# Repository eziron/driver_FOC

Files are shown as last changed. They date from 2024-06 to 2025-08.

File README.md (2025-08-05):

# EZFOC V1 - Controlador FOC para Motores Brushless

<p align="center">
  Vista frontal de la PCB EZFOC V1 ensamblada
  <br>
  <em>Vista frontal de la PCB EZFOC V1 completamente ensamblada.</em>
</p>

---

## 📜 Descripción General

**EZFOC V1** es mi proyecto de título con el cual obtuve el grado de Ingeniero de Ejecución en Electrónica. El proyecto se enfoca en el diseño, implementación y validación de un controlador de campo orientado (FOC) para motores brushless (BLDC), desarrollado desde cero abarcando tanto el diseño del **hardware (PCB)** como la programación del **firmware** en un microcontrolador de alto rendimiento **STM32H743VIT6**.

El principal objetivo del proyecto fue ofrecer una solución robusta y de altas prestaciones para aplicaciones exigentes, como la **robótica de competencia (robots de sumo)**, donde el control preciso de torque y velocidad, junto con la capacidad de manejar altas corrientes, es fundamental.

Para una referencia completa y detallada, puedes consultar el **[Esquemático del Hardware](esquematico%20PCB.pdf)** y el **[Manuscrito del Proyecto de Título](manuscrito%20Driver%20FOC%20rev%203%20300325.pdf)**, ambos disponibles en la raíz de este repositorio.

### ✨ Características Principales

*   **Control FOC (Field-Oriented Control):** Permite un control de torque suave y eficiente, desacoplando el flujo magnético del par motor.
*   **Hardware Personalizado:**
    *   PCB de 4 capas diseñada en Autodesk Eagle. Una parte del ensamblaje se realizó mediante el servicio de **PCBA de JLCPCB**, mientras que los componentes restantes fueron soldados manualmente.
    *   Inversor trifásico capaz de manejar altas corrientes (hasta 100A continuos por diseño, con MOSFETs en paralelo).
    *   Medición de corriente de fase **en línea (inline)**, a la salida de cada pierna del inversor, con resistencias shunt y amplificadores INA240.
    *   Soporte para encoder magnético (AS5047P) para una realimentación de posición precisa.
*   **Firmware de Alto Rendimiento:**
    *   Basado en un microcontrolador **STM32H743VIT6** (ARM Cortex-M7 @ 480 MHz).
    *   Lazo de control ejecutado a **48 kHz** en una interrupción de alta prioridad para garantizar el tiempo real.
    *   Uso intensivo de periféricos como Timers, ADC y DMA para minimizar la carga de la CPU.
    *   Comunicación USB (Virtual COM Port) para depuración y visualización de datos en tiempo real.
*   **Diseño Mecánico:** Incluye soportes y acoples para el motor y el encoder diseñados en Autodesk Inventor e impresos en 3D.

---

## 📂 Estructura del Repositorio

El repositorio está organizado en varios directorios clave que separan las diferentes partes del proyecto. Para un acceso rápido, el **esquemático final** (`esquematico PCB.pdf`) y el **manuscrito del proyecto** (`manuscrito Driver FOC...pdf`) se encuentran en la raíz del repositorio.

```
.
├── Firmware_H7/      # Código fuente del firmware para el STM32H7.
├── Hardware/         # Archivos de diseño de la PCB y modelos 3D.
├── datasheets/       # Hojas de datos de los componentes principales.
├── manuscrito/       # Documento de la tesis, gráficos y datos de validación.
├── fotos/            # Fotografías del hardware y montaje.
├── referencias/      # Documentos de referencia y papers utilizados.
└── util/             # Scripts y utilidades para depuración y análisis de datos.
```

### 🧠 `Firmware_H7`

Contiene todo el código fuente para el microcontrolador. El entorno de desarrollo es **VSCode** con la extensión `stm32-for-vscode`.

*   `Board/`: **Lógica de aplicación principal.** Aquí se implementan los módulos clave del controlador:
    *   `FOC.c/.h`: Algoritmo central de FOC (transformadas de Clarke, Park, etc.).
    *   `PID.c/.h`: Controladores PID para los lazos de corriente y velocidad.
    *   `encoder.c/.h`: Lógica para la lectura y procesamiento de datos del encoder.
    *   `state_machine.c/.h`: Máquina de estados para gestionar el funcionamiento del motor (calibración, run, stop).
*   `Core/`: Código base generado por **STM32CubeMX**.
    *   `Src/main.c`: Punto de entrada principal y bucle de baja prioridad.
    *   `Src/stm32h7xx_it.c`: Rutinas de servicio de interrupción (aquí vive el lazo FOC).
*   `Makefile` y `STM32-for-VSCode.config.yaml`: Archivos de configuración para la compilación gestionada por la extensión de VSCode.

### 🛠️ `Hardware`

Todos los archivos de diseño de la placa controladora "EZFOC V1".

*   `3D/`: Archivos de diseño mecánico (`.ipt`, `.iam` de Inventor) y modelos para impresión 3D (`.stl`) del soporte motor-encoder.
*   `EZFOC_V1.sch` y `EZFOC_V1.brd`: Archivos de esquemático y PCB de Autodesk Eagle.
*   `EZFOC_V1_bom.csv` y `EZFOC_V1_cpl.csv`: Lista de materiales (BOM) y archivo de posicionamiento (CPL) para el ensamblaje automatizado.
*   `libs/`: Librerías de componentes para Eagle, obtenidas de diversas fuentes y con algunas modificaciones menores.

### 📊 `manuscrito` y `util`

*   **`manuscrito/`**: Contiene el documento de la tesis en formato LaTeX (`.tex`), junto con todas las imágenes, gráficos y datos (`.csv`) utilizados para la validación del controlador.
*   **`util/`**: Herramientas de apoyo desarrolladas en Python.
    *   `debug_FOC.py`: Script para recibir datos del microcontrolador vía USB, graficarlos en tiempo real y guardarlos en CSV.
    *   `reloj bruto.py`: Script auxiliar para calcular y obtener las configuraciones de los PLLs para el sistema de reloj del STM32H7.
    *   `Debug_LOGS/`: Logs de datos capturados durante las pruebas.

---

## 🚀 Configuración y Uso

Este proyecto está configurado para ser compilado utilizando **Visual Studio Code** con la extensión `stm32-for-vscode`.
(idealmente en linux o wsl)

### Requisitos de Software

1.  **Visual Studio Code**: El editor principal.
2.  **Extensión `stm32-for-vscode`**: Búscala e instálala desde el marketplace de VSCode.
3.  **ARM GCC Toolchain**: El compilador. La extensión `stm32-for-vscode` suele guiar en su instalación.
4.  **STM32CubeProgrammer**: Herramienta para flashear el firmware en el microcontrolador.

---

## 📈 Futuras Mejoras y Problemas Conocidos

Este proyecto sienta una base sólida, pero existen varias áreas de mejora identificadas durante el desarrollo:

*   **Protección de Hardware**: Implementar un gate driver con protección anti-*shoot-through* integrada para mejorar la robustez del puente H.
*   **Optimización de Firmware**: Migrar el código a C++ y utilizar un sistema operativo de tiempo real como **FreeRTOS** para una mejor organización y escalabilidad.
*   **Filtrado de Señal**: Mejorar el filtrado de la corriente, ya sea con filtros analógicos pasivos en la PCB o algoritmos de filtrado digital más avanzados.
*   **Compensación de *Cogging Torque***: Implementar un algoritmo de calibración para reducir las vibraciones del motor a bajas velocidades.

## ✒️ Autor

*   **Rodrigo Fuentes Pedreros** - [eziron](https://github.com/eziron)

Un proyecto desarrollado para la **Universidad del Bío-Bío, Facultad de Ingeniería**.

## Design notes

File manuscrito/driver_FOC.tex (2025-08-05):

\documentclass[11pt]{report}
\usepackage[spanish]{babel}
\usepackage[utf8]{inputenc}
\usepackage{graphicx}
\usepackage{geometry}
\usepackage{fancyhdr}
\usepackage{amsmath}
\usepackage{helvet}
\usepackage{titlesec}
\usepackage{setspace}
\usepackage{tocloft}
\usepackage{hyperref}
\usepackage{csquotes}
\usepackage{placeins}

\usepackage{pdfpages}

\setlength{\parskip}{0.5em}

\usepackage[style=numeric,sorting=none]{biblatex}
\addbibresource{referencias.bib}

\onehalfspacing
\renewcommand{\familydefault}{\sfdefault}

\geometry{
  letterpaper,
  left=3cm,
  right=2cm,
  top=2.5cm,
  bottom=2cm,
}

\addto\captionsspanish{
  \renewcommand{\contentsname}{Índice}
  \renewcommand{\tablename}{Tabla}
}
\renewcommand{\cftchapdotsep}{\cftdotsep}  % Para capítulos
\renewcommand{\cftsecdotsep}{\cftdotsep}   % Para secciones
\renewcommand{\cftsubsecdotsep}{\cftdotsep} % Para subsections

\titleformat{\chapter}[display]
  {\normalfont\Large\bfseries}
  {\chaptername\ \thechapter}
  {10pt}
  {\huge}
\titlespacing*{\chapter}{0pt}{-20pt}{20pt}  % Ajusta el espaciado aquí

\begin{document}

% Title page
\begin{titlepage}
	\begin{center}
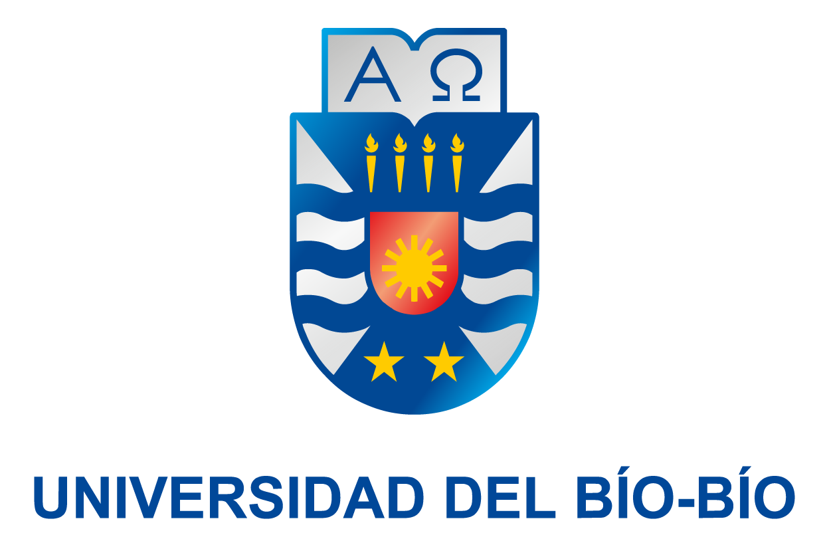
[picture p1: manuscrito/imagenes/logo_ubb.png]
		\\
		\normalsize FACULTAD DE INGENIERÍA\\
		DEPTO. INGENIERÍA ELÉCTRICA Y ELECTRÓNICA\\[2cm]

		\LARGE \textbf{``Implementación de un Controlador FOC para Motores Brushless con Encoder Utilizando STM32''}\\[6cm]

		\normalsize AUTOR:\\
		RODRIGO FUENTES PEDREROS\\
		\href{https://www.youtube.com/watch?v=dQw4w9WgXcQ}{\phantom{ASDF}}\\[2cm]

		SEMINARIO PARA OPTAR AL TÍTULO DE\\
		INGENIERO DE EJECUCIÓN EN ELECTRÓNICA\\[1cm]

		CONCEPCIÓN - CHILE\\
		AÑO 2024\\
	\end{center}
\end{titlepage}

% Back title page
\begin{titlepage}
	\begin{center}
		\\
		\normalsize FACULTAD DE INGENIERÍA\\
		DEPTO. INGENIERÍA ELÉCTRICA Y ELECTRÓNICA\\[2cm]

		\LARGE \textbf{``Implementación de un Controlador FOC para Motores Brushless con Encoder Utilizando STM32''}\\[5cm]

		\normalsize AUTOR\\
		RODRIGO FUENTES PEDREROS\\[3cm]

		\large PROFESOR GUÍA:\\
		\large ANGEL ERNESTO RUBIO\\[1cm]
		\large PROFESORES GUÍA ADJUNTO:\\
		\large PEDRO \href{https://youtu.be/UJwA7hu3aug?si=OvcJZs2QosQupum7&t=50}{MELIN} COLOMA
	\end{center}
\end{titlepage}

\normalsize
\pagenumbering{arabic}
\setcounter{page}{3}

\newpage
\tableofcontents

\newpage
\listoffigures

%\newpage
\listoftables

\newpage
\chapter*{Resumen}
\addcontentsline{toc}{chapter}{Resumen}

Este trabajo aborda el diseño e implementación de un controlador de campo orientado (\emph{FOC}) para motores \emph{brushless} de corriente continua, incorporando un \emph{encoder} para la medición de la posición. En primera instancia, se revisan los fundamentos teóricos que sustentan la técnica \emph{FOC}, destacando su capacidad para desacoplar el flujo magnético del par motor, y la relevancia de las transformadas de Clarke y Park para simplificar el control de las corrientes en el estátor. Asimismo, se incluyen los conceptos principales de la Modulación por Vector Espacial (\emph{SVM}), esencial para la síntesis de las señales de salida del inversor.

Posteriormente, se detalla el diseño y la fabricación del \emph{hardware} de la solución, que comprende un inversor trifásico basado en MOSFETs, controladores de puerta (\emph{gate drivers}) y sensores de corriente de tipo \emph{shunt}, junto con los elementos de filtrado y protección necesarios. Se selecciona y acondiciona un motor \emph{brushless}, al cual se integra un \emph{encoder} magnético para la obtención de la posición del rotor. Además, se documentan los procesos de elaboración de la PCB y la disposición de sus pistas para manejar corrientes elevadas, considerando la disipación y la estabilidad del sistema.

En el ámbito del \emph{firmware}, se describen las estrategias de configuración de los periféricos del microcontrolador STM32, haciendo uso de \emph{STM32CubeMX} para la inicialización de temporizadores y convertidores A/D (\emph{ADC}). Se explica el flujo de ejecución principal y la rutina de interrupción encargada de efectuar la lectura de sensores, la aplicación de las transformadas de Clarke y Park, los controladores de corriente y velocidad, así como la generación de las señales PWM mediante \emph{SVM}.

Para validar el rendimiento del controlador, se efectúan pruebas de velocidad y par bajo distintas condiciones de carga, analizando la estabilidad de las corrientes y la rapidez de respuesta ante cambios en la referencia. Asimismo, se capturan datos en tiempo real para su posterior evaluación, confirmando que la implementación logra un control estable y preciso del motor. Se identifican, no obstante, algunos retos en escenarios extremos, motivando la propuesta de futuras mejoras en el diseño.

En síntesis, la solución presentada demuestra la factibilidad de implementar un controlador \emph{FOC} de altas prestaciones utilizando un STM32 de la serie H7, combinando técnicas de transformación en el dominio rotatorio y \emph{SVM} en el lazo de control. Las observaciones obtenidas abren la puerta a nuevas optimizaciones, tanto en el \emph{hardware} (filtrado, disipación y protección) como en el \emph{firmware} (estructuras de software, algoritmos de compensación y sistemas operativos en tiempo real), facilitando así el despliegue de aplicaciones en robótica competitiva y sistemas embebidos.

\newpage
\chapter{Introducción}
\section{Introducción general}
Cuando se habla de motores eléctricos de corriente continua, los motores sin escobillas destacan por su alto desempeño, siendo la opción preferida en aplicaciones como vehículos eléctricos, drones, robótica avanzada y robótica industrial.

Para los motores \textit{brushless}, existe una gran variedad de técnicas de control. Algunas de las más relevantes son el control trapezoidal, utilizado mayormente en drones; el control directo de torque (DTC), empleado principalmente en motores de media y alta potencia en ambientes industriales; y el control FOC, que se aplica mayormente en robótica. En este documento, se tratará únicamente esta última técnica.

Existen tres aspectos clave que diferencian cada técnica: el rizado de torque, el coste computacional y la complejidad del hardware necesario para su ejecución. En estos aspectos, el control FOC es uno de los que produce menor rizado de torque, aunque requiere un mayor coste computacional y hardware especializado.

Este proyecto presenta la implementación y validación de un controlador de campo orientado (FOC) para motores sin escobillas de corriente continua (BLDC). Además, se desarrolló la placa controladora utilizando un microcontrolador STM32 como núcleo principal.

\newpage
\section{Marco teórico}
\subsection{Motores \textit{brushless}}
Los motores \textit{brushless}, o motores sin escobillas de corriente continua (BLDC), son un tipo de motor trifásico síncrono que utiliza imanes permanentes en el rotor y bobinas en el estátor, el cual está formado por láminas de hierro con ranuras para alojar las bobinas. A diferencia de los motores de corriente continua con escobillas, los BLDC no emplean elementos mecánicos para conmutar la corriente en las bobinas. En su lugar, esta conmutación se realiza mediante un controlador electrónico \cite{frick2018bldc}, eliminando el rozamiento y el desgaste asociados a las escobillas, lo que mejora la eficiencia del sistema.

\begin{figure}[ht]
	\centering
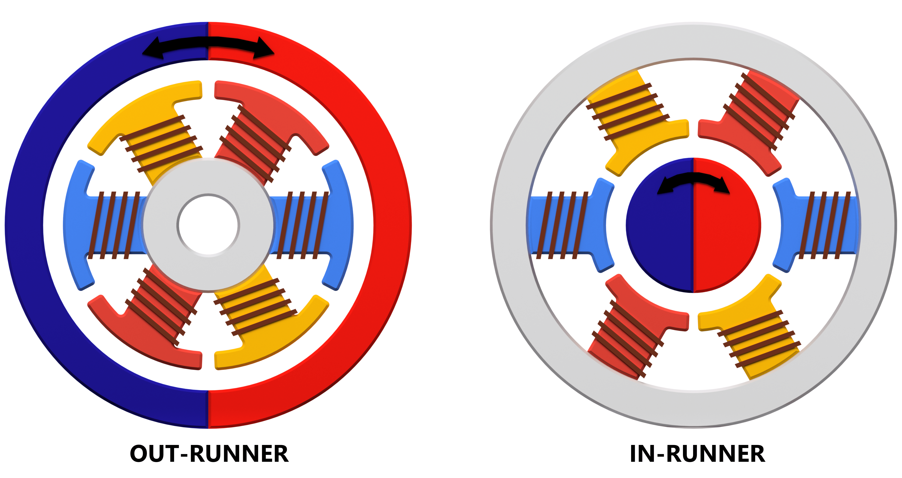
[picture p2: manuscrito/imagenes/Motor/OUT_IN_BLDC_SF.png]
	
	\caption{Esquema de motores sin escobillas (\textit{BLDC}).}
	\label{fig:motor_sin_escobillas}
\end{figure}
\FloatBarrier

Similar a los motores trifásicos de corriente alterna, estos pueden tener configuraciones de bobinado en delta o estrella \cite{Millet2022}. Además, como se ejemplifica en la figura \ref{fig:motor_sin_escobillas}, pueden presentar configuraciones \textit{in-runner}, donde los imanes están en el centro del eje con las bobinas en el exterior, o configuraciones \textit{out-runner} , donde los imanes se encuentran por fuera del motor, mientras que las bobinas están en el centro \cite{9774372}. Estos motores, al requerir una sincronización entre el campo magnético del estátor y el campo magnético del rotor, suelen utilizar encoders o sensores de efecto Hall para obtener información sobre la posición del eje y, de este modo, mantener una conmutación adecuada. No obstante, también es posible emplear técnicas \textit{sensorless} (sin sensor) para estimar la posición del rotor sin necesidad de sensores físicos \cite{Gualtieri2018_STEP}.

Los \textit{BLDC} se destacan por ofrecer una mayor densidad de potencia, mayor torque, mejores eficiencias y pueden alcanzar velocidades más altas. Sin embargo, al requerir de un controlador electrónico que se encargue de la conmutación para generar el movimiento del rotor, la complejidad y los costos asociados a su implementación son mayores \cite{AN885}.

\newpage
\subsection{Control Orientado de Campo (FOC)}
El control orientado de campo se basa en desacoplar el flujo electromagnético del par motor, permitiendo el control independiente de cada uno, aunque en este caso se realiza de forma indirecta, trabajando con las corrientes del estátor en vez de las variables reales de flujo y par. Este desacoplamiento se logra mediante la transformación de las variables trifásicas del motor, que están en un marco de referencia estacionario \(ABC\), hacia un marco de referencia rotatorio \(dq\) que gira en sincronía con el rotor del motor \cite{power_conv_14}.

\begin{figure}[ht]
	\centering
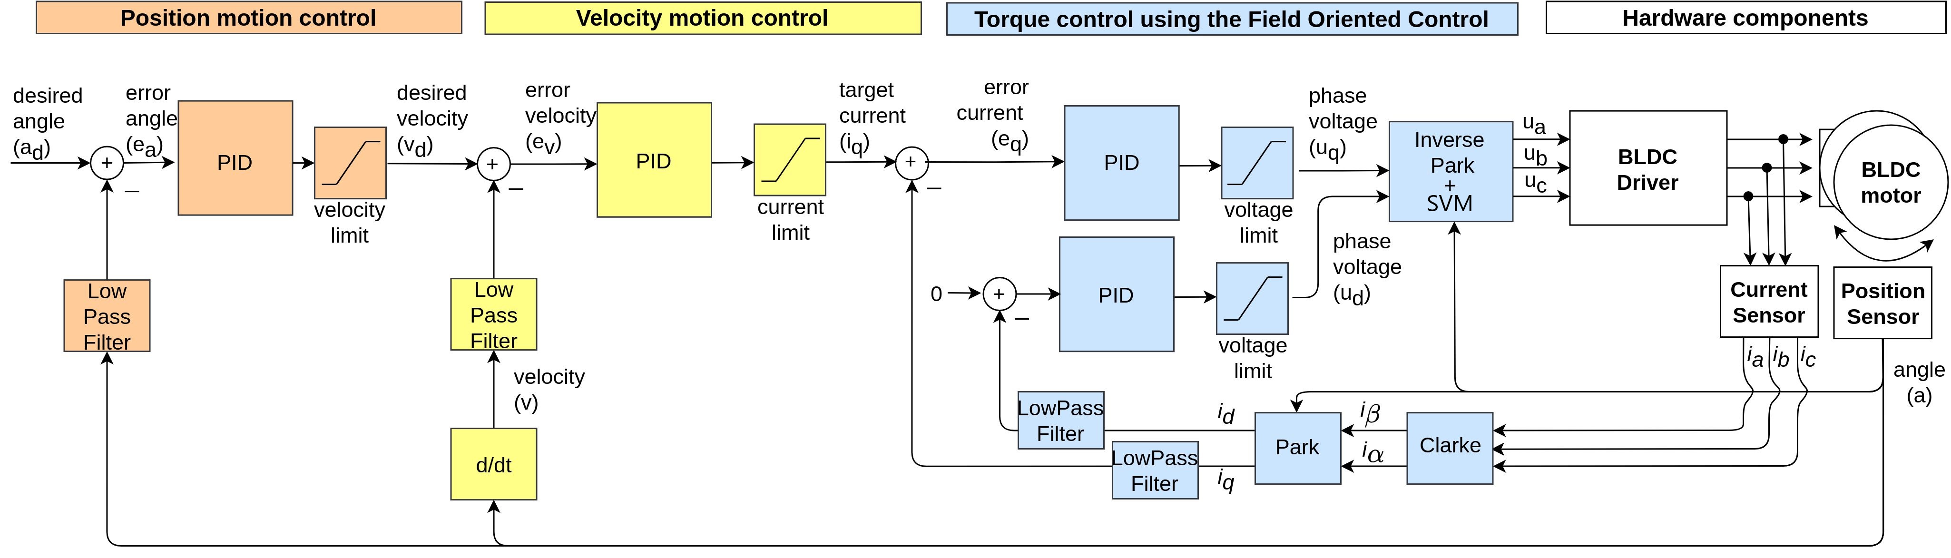
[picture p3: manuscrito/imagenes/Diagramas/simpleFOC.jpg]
	
	\caption{Diagrama de flujo del control FOC\cite{Skuric_SimpleFOC_A_Field_2022}.}
	\label{fig:foc_transform}
\end{figure}
\FloatBarrier

La figura \ref{fig:foc_transform} presenta el diagrama de flujo base de un controlador FOC, con sus elementos esenciales, donde podemos apreciar la separación por hardware, controladores de corriente, además de los controladores de velocidad y posición. La transformación entre los marcos de referencia se realiza aplicando la transformada de Clarke y la transformada de Park. De esta forma, las mediciones de corriente que presentan un comportamiento oscilatorio en el tiempo se convierten en variables de corriente continua, lo que virtualmente emula el funcionamiento de un motor con escobillas a nivel de los controladores\cite{power_conv_14}. Posteriormente, se aplican los controladores de corriente y velocidad para obtener las señales de control necesarias para el inversor trifásico.

\newpage
\subsection{Transformada de Clarke}
La transformada de Clarke convierte un sistema trifásico de corrientes \(ABC\) en un sistema bifásico \(\alpha\beta\), proyectando las corrientes en un sistema de coordenadas bidimensional estacionario. Esta transformación simplifica el análisis al reducir las tres corrientes de fase a dos componentes ortogonales, manteniendo la información esencial del sistema original \cite{AN1078}.

\begin{figure}[ht]
	\centering
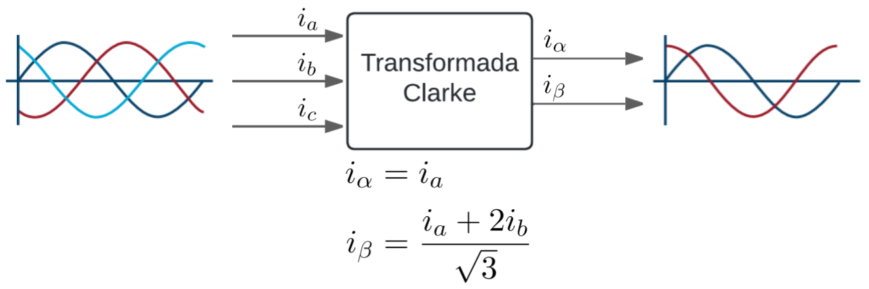
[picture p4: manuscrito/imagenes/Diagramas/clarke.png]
	
	\caption{Esquema transformada de Clarke.}
	\label{fig:clarke_transform}
\end{figure}
\FloatBarrier

En la figura \ref{fig:clarke_transform} se ilustra la representación gráfica de las corrientes de entrada \(i_a, i_b, i_c\) y las corrientes de salida \(i_\alpha, i_\beta\). Además, se incluyen las ecuaciones necesarias para llevar a cabo la transformación.

\subsection{Transformada de Park}
La transformada de Park convierte el sistema en el marco de referencia estacionario \(\alpha\beta\) en el sistema en el marco de referencia rotatorio \(dq\) sincronizado con el ángulo del rotor\cite{AN1078}.

\begin{figure}[ht]
	\centering
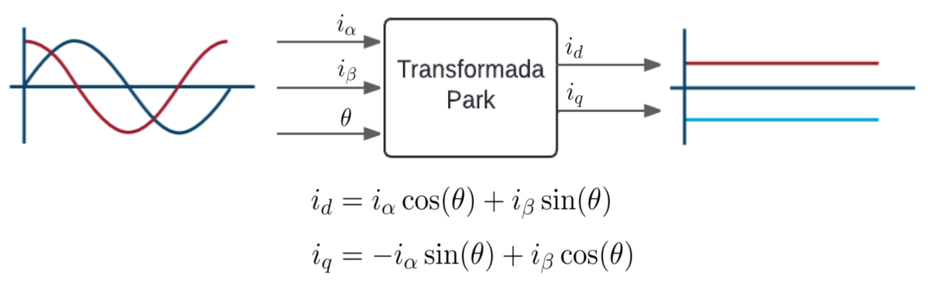
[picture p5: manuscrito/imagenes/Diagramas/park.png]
	
	\caption{Esquema transformada de Park.}
	\label{fig:park_transform}
\end{figure}
\FloatBarrier

En la figura \ref{fig:park_transform} se muestra gráficamente cómo las variables \(\alpha, \beta\) se transforman a \(d, q\), junto con las ecuaciones empleadas para llevar a cabo esta transformación.

\subsection{Transformada inversa de Park}
La transformada inversa de Park convierte el sistema en el marco de referencia rotatorio \(dq\) de vuelta al marco de referencia estacionario \(\alpha\beta\) \cite{AN1078}.

\begin{figure}[ht]
	\centering
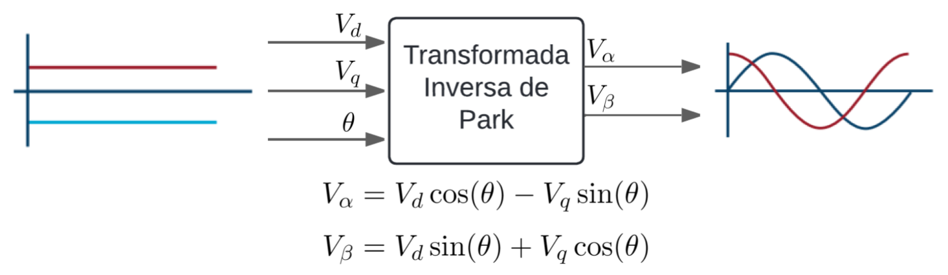
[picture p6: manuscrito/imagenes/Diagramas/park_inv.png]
	
	\caption{Esquema transformada inversa de Park.}
	\label{fig:park_inv_transform}
\end{figure}
\FloatBarrier

En la figura \ref{fig:park_inv_transform} se ilustra cómo las variables \(d, q\) se transforman nuevamente a \(\alpha, \beta\), con las ecuaciones correspondientes a este proceso inverso.

\subsection{Modulación de Espacio Vectorial (SVM)}
La Modulación por Vector Espacial (SVM) es una técnica utilizada para el control digital de inversores de voltaje. Representa todos los estados de conmutación del inversor como vectores de voltaje en el plano $\alpha$-$\beta$, formando un hexágono regular dividido en seis sectores o sextantes, como se puede ver en la figura \ref{fig:sectantes}. Estos se utilizan para sintetizar el vector de referencia $\mathbf{V}_{\text{ref}}=(V_{\alpha},V_{\beta})$ mediante una suma ponderada de los vectores de voltaje adyacentes en el sextante donde se encuentre, para finalmente calcular los tiempos de activación necesarios en cada fase del inversor, logrando una aproximación más \href{https://www.youtube.com/watch?v=NY0ffyEu6uo}{precisa} de la señal deseada.

%\begin{figure}[ht]
%	\centering
%	\includegraphics[width=0.6\textwidth]{imagenes/Diagramas/SVM.png}
%	\caption{Esquema SVM.}
%	\label{fig:esquema_svm}
%\end{figure}
%\FloatBarrier

\begin{figure}[ht]
	\centering
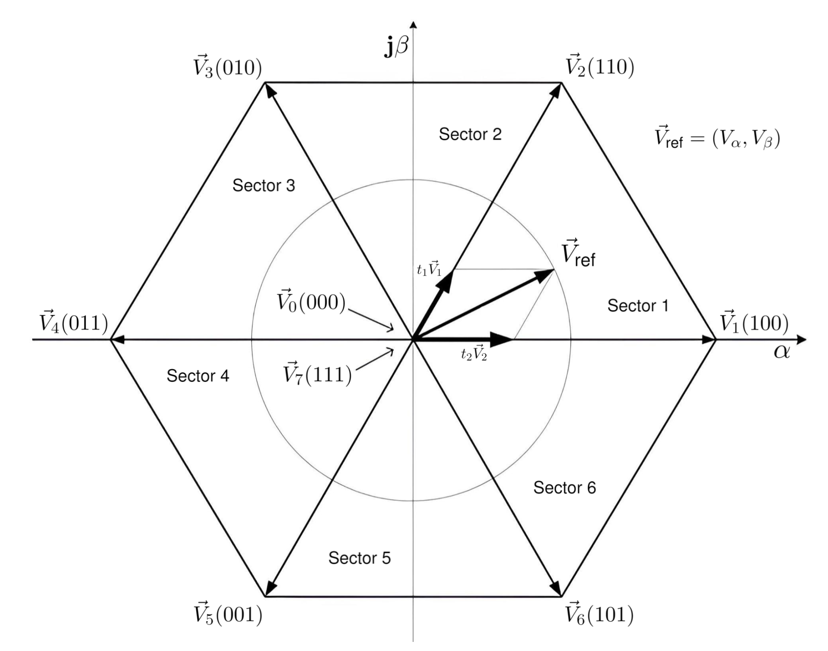
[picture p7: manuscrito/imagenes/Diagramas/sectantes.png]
	
	\caption{Sextantes en SVM.}
	\label{fig:sectantes}
\end{figure}
\FloatBarrier

%Se utiliza un patrón de activación específico que permite minimizar la frecuencia de conmutación de los transistores, aprovechando estados redundantes para reducir las pérdidas asociadas a la conmutación y mejorar la eficiencia del sistema\cite{power_conv_06}, como se muestra en la tabla \ref{tabla_svm}, la secuencia de activación es especifica para cada sextante.

%\begin{table}[htbp]
%	\centering
%	\caption{Secuencia de Conmutación en SVM}
%	\begin{tabular}{ c c c c c c c c }
%		\hline
%		\textbf{Sector} & \textbf{1}       & \textbf{2}       & \textbf{3}       & \textbf{4}       & \textbf{5}       & \textbf{6}       & \textbf{7}       \\
%		\hline
%		I               & $\vec{V}_0(000)$ & $\vec{V}_1(100)$ & $\vec{V}_2(110)$ & $\vec{V}_7(111)$ & $\vec{V}_2(110)$ & $\vec{V}_1(100)$ & $\vec{V}_0(000)$ \\
%		II              & $\vec{V}_0(000)$ & $\vec{V}_3(010)$ & $\vec{V}_2(110)$ & $\vec{V}_7(111)$ & $\vec{V}_2(110)$ & $\vec{V}_3(010)$ & $\vec{V}_0(000)$ \\
%		III             & $\vec{V}_0(000)$ & $\vec{V}_3(010)$ & $\vec{V}_4(011)$ & $\vec{V}_7(111)$ & $\vec{V}_4(011)$ & $\vec{V}_3(010)$ & $\vec{V}_0(000)$ \\
%		IV              & $\vec{V}_0(000)$ & $\vec{V}_5(001)$ & $\vec{V}_4(011)$ & $\vec{V}_7(111)$ & $\vec{V}_4(011)$ & $\vec{V}_5(001)$ & $\vec{V}_0(000)$ \\
%		V               & $\vec{V}_0(000)$ & $\vec{V}_5(001)$ & $\vec{V}_6(101)$ & $\vec{V}_7(111)$ & $\vec{V}_6(101)$ & $\vec{V}_5(001)$ & $\vec{V}_0(000)$ \\
%		VI              & $\vec{V}_0(000)$ & $\vec{V}_1(100)$ & $\vec{V}_6(101)$ & $\vec{V}_7(111)$ & $\vec{V}_6(101)$ & $\vec{V}_1(100)$ & $\vec{V}_0(000)$ \\
%		\hline
%	\end{tabular}
%	\label{tabla_svm}
%\end{table}
%cuarto párrafo

\newpage
\section{Motivación}
Este proyecto nace de la necesidad de un controlador para motores brushless adecuado para su uso en robots de competencia en la categoría de robot sumo autónomo. En esta categoría, este tipo de motores no son normalmente utilizados debido a las limitaciones de los controladores comerciales y los riesgos que conlleva la sobrecarga de los motores en periodos cortos de acción, ya que los \href{https://www.youtube.com/watch?v=SmDZmGU08BM}{controladores comerciales} no están pensados para esto.

\section{Objetivos}
\subsection{Objetivo General}
Implementar un controlador de tipo FOC (Control de Campo Orientado) para motores brushless con encoder, utilizando un microcontrolador STM32, que sirva de base para un driver especializado en la robótica competitiva.

\subsection{Objetivos Específicos}
\begin{itemize}
	\item Estudiar los principios del Control de Campo Orientado (FOC) y la modulación de espacio vectorial (SVM) para aplicarlos en el diseño del controlador.
	\item Diseñar el hardware para el controlador FOC, con los componentes mínimos necesarios para validar el funcionamiento.
	\item Configurar y programar el microcontrolador para el algoritmo FOC, utilizando las librerías HAL de STM32.
	\item Validar el funcionamiento del controlador y proponer posibles mejoras para su aplicación en robótica competitiva.
\end{itemize}

\newpage
\subsection{Alcances}
\begin{itemize}
	\item Se configurará el microcontrolador utilizando STM32CubeMX.
	\item Se implementará el controlador de velocidad y corriente.
	\item No se implementará el control de posición.
	\item Se programará el firmware utilizando VScode y el lenguaje C.
	\item El firmware se compilará utilizando un makefile y GCC, junto con la extensión STM32 for VScode.
	\item Se cargará el firmware utilizando STM32CubeProgrammer y ST-link.
	\item Se diseñará la PCB en Eagle.
	\item Se diseñarán las piezas adicionales en Autodesk Inventor para su posterior fabricación mediante impresión 3D.
	\item La PCB se fabricará y semi ensamblará utilizando \href{https://www.youtube.com/watch?v=riT4nl0T8_M}{JLCPCB}.
	\item Se obtendrán datos detallados durante el tiempo de ejecución.
	\item Los datos se graficarán utilizando Plotly en Python.
	\item Se identificarán posibles mejoras.
\end{itemize}

\chapter{Hardware}
\section{Introducción}
Este capítulo busca documentar el desarrollo e implementación de todo el hardware y electrónica necesaria para el controlador FOC, partiendo de la revisión de los parámetros principales y componentes utilizados, para finalmente revisar a grandes rasgos el diseño de la placa controladora.

\begin{figure}[ht]
	\centering
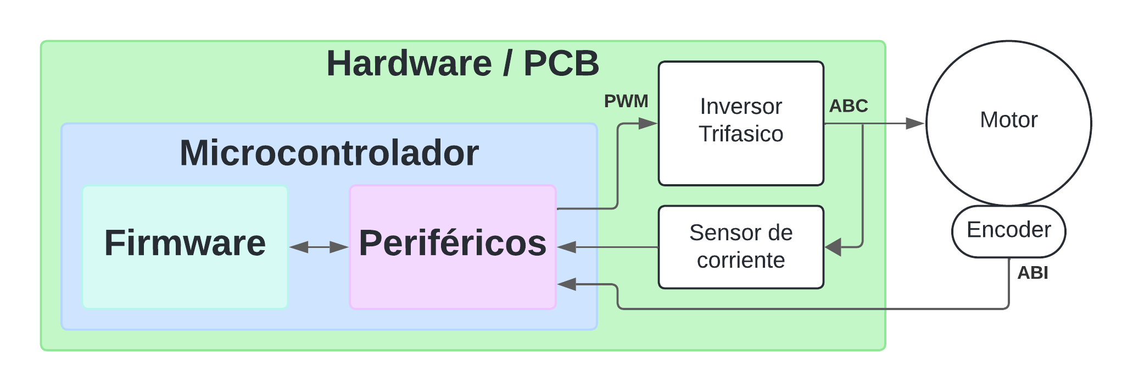
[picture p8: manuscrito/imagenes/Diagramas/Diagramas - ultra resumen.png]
	
	\caption{Diagrama Resumido del sistema.}
	\label{flujo_resumen}
\end{figure}
\FloatBarrier

En la Figura \ref{flujo_resumen} se muestra una vista general de la interacción entre los bloques principales del controlador. El microcontrolador, programado con el firmware que utiliza los periféricos para generar las señales PWM necesarias para conducir el inversor trifásico, se encarga de suministrar la corriente al motor y adquirir las mediciones de corriente de las fases, así como la posición del rotor a través del encoder. De esta manera se cierra el lazo de control FOC.

\newpage
\section{Desarrollo del Hardware}

En esta sección se describen de manera resumida los componentes esenciales que integran el controlador, ilustrados en la Figura \ref{flujo_resumen_hardware}.

\begin{figure}[ht]
	\centering
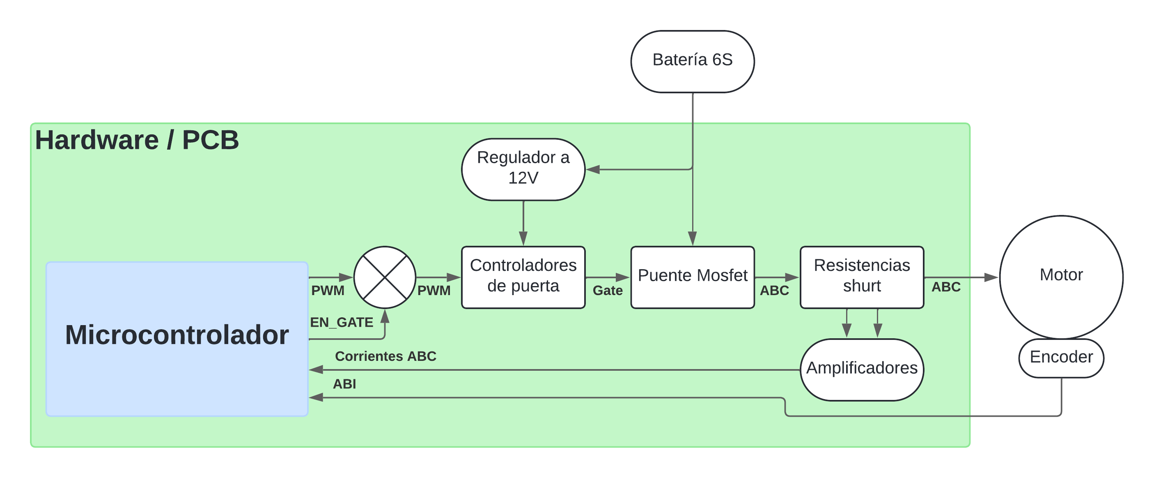
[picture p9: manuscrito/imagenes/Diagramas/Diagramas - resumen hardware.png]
	
	\caption{Diagrama resumido del hardware.}
	\label{flujo_resumen_hardware}
\end{figure}

A continuación se presenta un listado con los principales componentes:

\begin{itemize}
    \item \textbf{Inversor Trifásico (Puente MOSFET):} Conmuta la tensión de la batería para generar señales trifásicas y controlar velocidad y par del motor.
    \item \textbf{Controladores de Puerta (\emph{Gate Drivers}):} Amplifican las señales PWM del microcontrolador para activar y desactivar los MOSFETs de forma eficiente.
    \item \textbf{Resistencias \emph{Shunt}:} Miden la caída de tensión en cada fase para obtener la corriente, esencial para el control FOC.
    \item \textbf{Motor Brushless (BLDC):} Motor síncrono trifásico sin escobillas que proporciona alta eficiencia y controlabilidad.
    \item \textbf{\emph{Encoder}:} Sensor de posición angular que informa de la posición y velocidad del rotor para una conmutación sincronizada.
    \item \textbf{Regulador de Voltaje 12V:} Fuente estable de 12V para alimentar correctamente los controladores de puerta.
    \item \textbf{Batería:} Proporciona la potencia principal al inversor, determinando el rendimiento y la autonomía del sistema.
\end{itemize}

\newpage
\subsection{Motor}

El punto de partida es la selección del motor, que define parámetros cruciales como corriente máxima, voltaje nominal y la velocidad máxima (\emph{Kv}). Estos influyen directamente en la elección de los MOSFETs y resistencias \emph{shunt} para manejar la corriente requerida.

\begin{figure}[ht]
	\centering
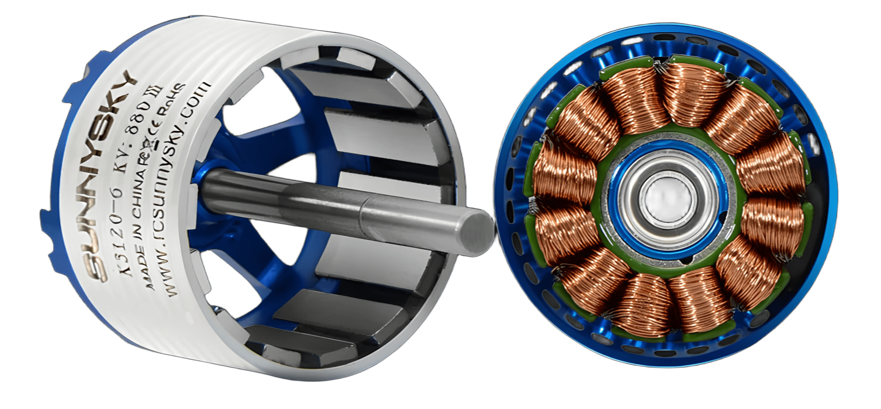
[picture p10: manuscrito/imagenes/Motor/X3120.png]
	
	\caption{SunnySky X3120 V3.}
	\label{X3120}
\end{figure}
\FloatBarrier
Se ha optado por utilizar el motor \textbf{SunnySky X3120 V3} de 585Kv para el diseño del controlador debido a su disponibilidad inmediata. Este es un motor principalmente orientado al uso en drones de tipo aeroplano, pero su gran potencia y bajo peso lo hacen ideal para su uso en robots sumo, como se puede ver en la figura \ref{X3120}. Se trata de un motor tipo outrunner, en el cual su eje se extiende y sale por la base del motor.

\begin{table}[h!]
	\centering
	\caption{Características del motor SunnySky X3120 V3 585Kv}
	\begin{tabular}{l l}
		\hline
		\textbf{Propiedad}               & \textbf{Valor} \\
		\hline
		Número de polos del rotor        & 14             \\
		Número de ranuras del estátor    & 12             \\
		Voltaje Nominal (celdas de Lipo) & 6S (22.2 V)    \\
		Constante de velocidad del motor & 585 $K_v$      \\
		Resistencia del motor            & 43.5 m$\Omega$ \\
		Corriente continua máxima        & 65 A/30 s      \\
		Potencia continua máxima         & 1625 W         \\
		Corriente en vacío               & 1.0 A/10 V     \\
		\hline
	\end{tabular}
\end{table}
\FloatBarrier

Algunos de los parámetros más relevantes para el diseño del hardware son el voltaje nominal, que está marcado como 6S (celdas de lipo). Las celdas de lipo varían su voltaje en función de su carga, teniendo un voltaje mínimo de 3V, nominal de 3.7V y máximo de 4.2V. Por esto, una batería de 6 celdas en serie corresponde a un voltaje mínimo de 18V, nominal de 22.2V y máximo de 25.2V. Otro parámetro importante es la corriente continua máxima de 65A.

\newpage
\subsection{Consideraciones para el Controlador Basadas en el Motor}

Tras la selección del motor SunnySky X3120 V3, es crucial revisar los parámetros clave que este impone al diseño del controlador, asegurando que los componentes seleccionados sean adecuados para las exigencias del motor.

El \textbf{voltaje máximo del motor} es de 25.2V, correspondiente a una batería LiPo 6S completamente cargada. Para los MOSFETs del inversor, es recomendable seleccionar dispositivos con un voltaje nominal superior al máximo esperado para proporcionar un margen de seguridad. En la práctica, el valor nominal más cercano y comúnmente utilizado es de \textbf{30V} para MOSFETs. De manera similar, los condensadores en el bus de voltaje deben soportar este voltaje máximo. Siguiendo las tablas de valores nominales estándar para capacitores, se deben utilizar condensadores con un voltaje nominal de al menos \textbf{35V}.

La \textbf{corriente continua máxima} del motor es de 65A. Para el diseño del puente MOSFET, es esencial considerar un margen de seguridad para evitar el sobrecalentamiento y asegurar la fiabilidad del sistema.  Un factor de seguridad común es multiplicar la corriente continua máxima del motor por un factor de al menos tres. Por lo tanto, el puente MOSFET debería ser capaz de soportar al menos \textbf{195A}. Este margen de seguridad garantiza que el controlador pueda manejar picos de corriente y operaciones continuas exigentes sin comprometer los componentes.

Finalmente, la \textbf{velocidad máxima teórica} del motor se puede estimar utilizando su constante \emph{Kv} (585 RPM/V) y el voltaje máximo de operación (25.2V).  Esto resulta en una velocidad teórica máxima de aproximadamente \textbf{14.742 RPM} (\(585 \frac{\text{RPM}}{V} \times 25.2 \text{V} \approx 14742 \text{RPM}\)). Esta velocidad máxima es importante para la selección del encoder, asegurando que pueda operar correctamente dentro de este rango de velocidades sin perder precisión o funcionalidad.

En la siguiente tabla se resumen estos parámetros y las consideraciones para la selección de componentes del controlador:

\begin{table}[h!]
	\centering
	\caption{Parámetros Requeridos para el Controlador Basados en el Motor SunnySky X3120 V3}
	\begin{tabular}{l l}
		\hline
		\textbf{Parámetro del Controlador}         & \textbf{Valor Mínimo Requerido}           \\
		\hline
		Voltaje Nominal de Operación         & 22.2V                 \\
		Voltaje Drain-Source MOSFET (\(V_{DS}\)) & $\geq$ 30V                   \\
		Corriente Drain-Source MOSFET (\(I_D\))          & $\geq$ 195A             \\
		Voltaje de los Capacitores          & $\geq$ 35V             \\
		Velocidad Máxima del Encoder          & $\geq$ 15,000 RPM             \\
		\hline
	\end{tabular}
	\label{tabla_parametros_controlador}
\end{table}
\FloatBarrier

\newpage
\subsection{Encoder}

El encoder es el encargado de proveer la información sobre la posición angular del rotor en el motor. Se utilizó el encoder magnético AS5047P (figura \ref{AS5047P}), el cual utiliza un imán especial con una polarización diametral en el eje del motor y un arreglo de sensores HAL internos, para poder medir e interpretar la posición angular del imán.

\begin{figure}[ht]
	\centering
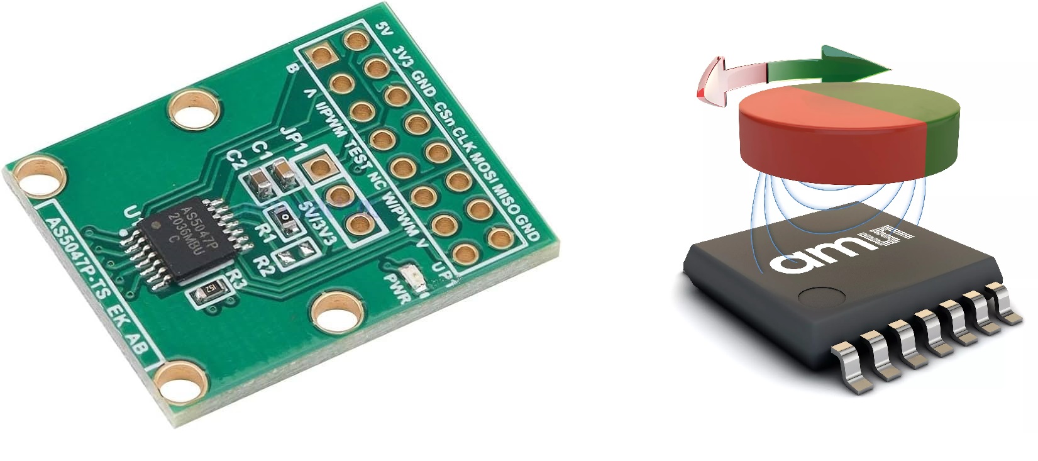
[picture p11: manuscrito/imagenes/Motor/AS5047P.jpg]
	
	\caption{AS5047P.}
	\label{AS5047P}
\end{figure}
\FloatBarrier

En esencia, este es un encoder absoluto que funciona principalmente a través de una comunicación SPI, pero opcionalmente incorpora una salida que imita el comportamiento de un encoder incremental con señal index, también conocidos como ABI o ABZ por sus señales. Los microcontroladores STM32 incorporan periféricos que pueden trabajar de forma nativa con estas señales sin mayor intervención del procesador, lo que simplifica en gran medida su implementación en comparación con el uso de SPI, aunque, en consecuencia, se pierden las capacidades de encoder absoluto.

\begin{table}[h!]
	\centering
	\caption{Características del encoder AS5047P}
	\begin{tabular}{l c c c l}
		\hline
		\textbf{Parámetro}            & \textbf{Mín} & \textbf{Típ} & \textbf{Máx} & \textbf{Unidad}      \\
		\hline
		Tensión de alimentación (LDO) & 4.5          & 5.0          & 5.5          & $\mathrm{V}$         \\
		Tensión de alimentación       & 3.0          & 3.3          & 3.6          & $\mathrm{V}$         \\
		Corriente de suministro       &              & 15           &              & $\mathrm{mA}$        \\
		Velocidad máxima              &              &              & 28000        & $\mathrm{RPM}$       \\
		Resolución del núcleo         &              & 14           &              & $\mathrm{bits}$      \\
		Resolución ABI                & 25           & 512          & 1024         & $\mathrm{PPR}$       \\
		Resolución ABI (X4)           & 100          & 2048         & 4096         & $\mathrm{Pasos/rev}$ \\
		\hline
	\end{tabular}
\end{table}
\FloatBarrier

\newpage
\subsection{Conjunto motor-encoder}
El encoder requiere estar fijo junto al motor y centrado respecto al eje de este para poder realizar su medición. Para ello, se diseñó en Autodesk Inventor y posteriormente se fabricó con impresión 3D un conjunto de soportes y sockets específicos para el motor-encoder.

\begin{figure}[ht]
	\centering
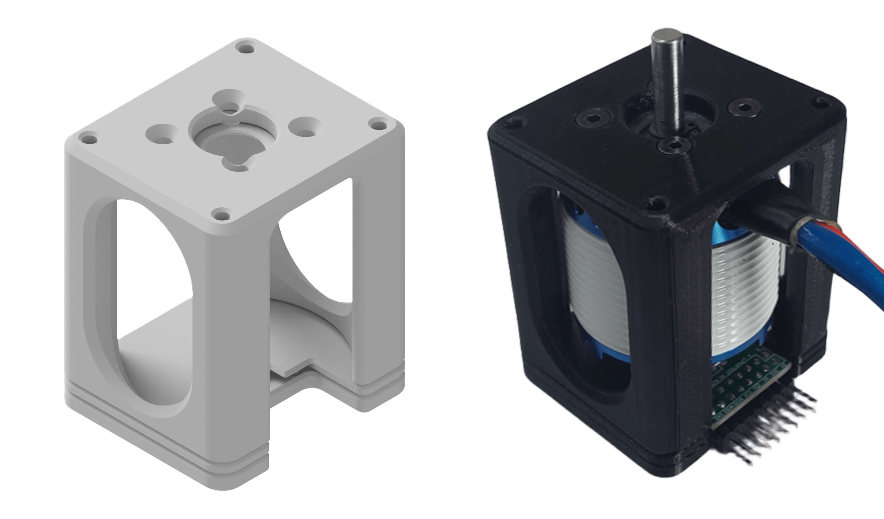
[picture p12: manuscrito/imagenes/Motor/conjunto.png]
	
	\caption{Montura motor-encoder.}
	\label{fig:Montura}
\end{figure}
\FloatBarrier

En la figura \ref{fig:Montura} se observa la \textbf{montura del motor y encoder}. Este conjunto de soporte sujeta el motor y se extiende hacia la parte trasera, de modo que mantiene el encoder firmemente posicionado.

\begin{figure}[ht]
	\centering
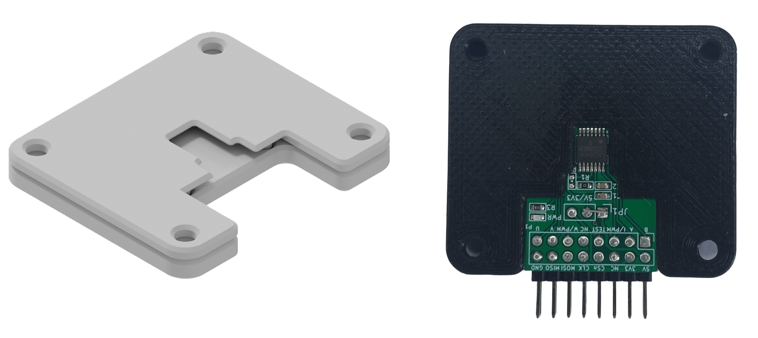
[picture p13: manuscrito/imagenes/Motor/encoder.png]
	
	\caption{Socket Encoder.}
	\label{fig:encoder}
\end{figure}
\FloatBarrier

En la figura \ref{fig:encoder} se muestra el \textbf{socket del encoder}. Este componente asegura que el chip del encoder quede correctamente alineado con el centro del eje del motor.

\begin{figure}[ht]
	\centering
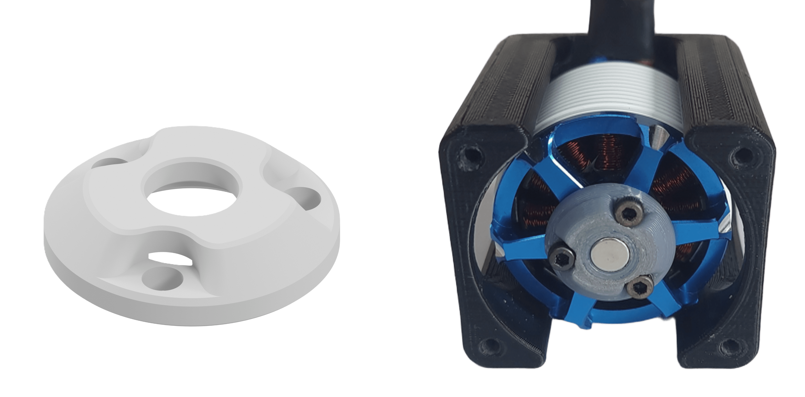
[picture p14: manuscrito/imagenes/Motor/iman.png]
	
	\caption{Socket imán axial.}
	\label{fig:iman}
\end{figure}
\FloatBarrier

Asimismo, se diseñó un \textbf{socket para el imán} (figura \ref{fig:iman}) con el fin de mantener el imán necesario para el funcionamiento del encoder perfectamente centrado en el eje del motor. Este socket se atornilla al rotor y está fabricado en ABS para resistir mejor las temperaturas elevadas que puedan generarse.

\newpage
\subsection{Puente Mosfet}

El puente mosfet es una de las partes del hardware más crítica. Este se encarga de realizar las conmutaciones en las fases del motor. Como se puede ver en la figura \ref{puente_MOSFET}, se divide en 3 piernas (o fases) iguales, donde cada pierna está conformada por 2 mosfets de tipo N en configuración push-pull, es decir, se tiene un mosfet alto conectado a $V+$ y un mosfet bajo conectado a $V-$. Cada mosfet tiene su propia señal de gate, las cuales se deben controlar de forma adecuada para evitar cortocircuitos. Es importante considerar que cada pierna del puente debe soportar por lo menos la corriente máxima del motor, aunque idealmente se deja un margen de seguridad de 2 a 3 veces la corriente máxima. Considerando la corriente de 65A del sunnysky X3120, los mosfets deberán soportar al menos 195A continuos y un voltaje Drain-source superior a los 25.2V para poder trabajar con la batería 6S.

\begin{figure}[ht]
	\centering
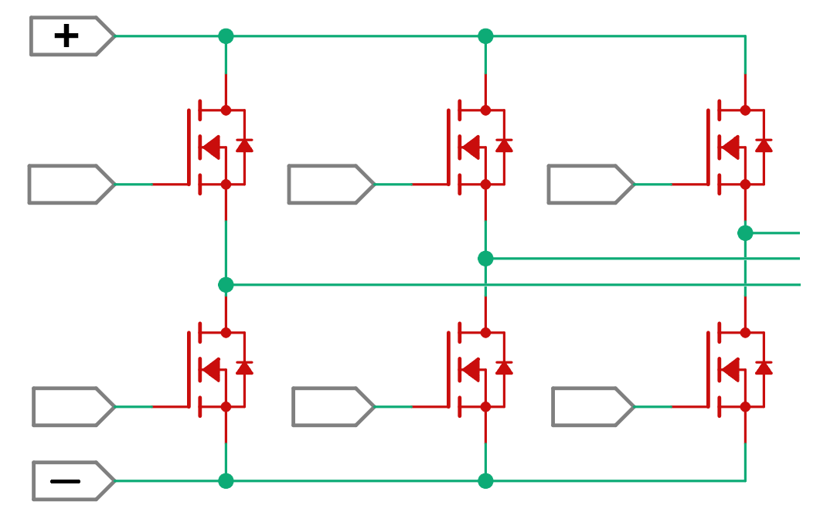
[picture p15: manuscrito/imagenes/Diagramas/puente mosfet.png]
	
	\caption{Esquema puente MOSFET.}
	\label{puente_MOSFET}
\end{figure}
\FloatBarrier

Se utilizó el mosfet \textbf{BSC011N03LSI} de la marca Infineon. Es un Mosfet de tipo N con un voltaje Drain-source de 30V. Estos mosfets soportan una corriente continua de 100A.

\begin{table}[h!]
	\centering
	\caption{Características del MOSFET BSC011N03LSI.}
	\begin{tabular}{l l c c c l}
		\hline
		\textbf{Parámetro}            & \textbf{Variable} & \textbf{Min} & \textbf{Typ} & \textbf{Max} & \textbf{Unidad}    \\
		\hline
		Tensión de drenaje-fuente     & $V_{DS}$          &              &              & 30           & $\mathrm{V}$       \\
		Resistencia encendido         & $R_{DS(on)}$      & 0.9          & 1.1          & 1.5          & $\mathrm{m\Omega}$ \\
		Corriente continua de drenaje & $I_D$             &              &              & 100          & $\mathrm{A}$       \\
		Corriente de pulso drenaje    & $I_{D,pulse}$     &              &              & 400          & $\mathrm{A}$       \\
		Tensión umbral del gate       & $V_{GS(th)}$      & 1.2          &              & 2            & $\mathrm{V}$       \\
		Carga de puerta total         & $Q_g$             &              & 34           & 45           & $\mathrm{nC}$      \\
		Potencia de disipación        & $P_{tot}$         &              &              & 96           & $\mathrm{W}$       \\
		\hline
	\end{tabular}
\end{table}
\FloatBarrier

\newpage
\subsection{Controladores de Puerta}

El controlador de puerta (\textit{gate driver}) se encarga de recibir las señales PWM provenientes del microcontrolador y, en consecuencia, activar o desactivar los MOSFETs en cada pierna del puente. Su función principal es proporcionar la corriente y el voltaje adecuados para encender y apagar rápidamente los MOSFETs, garantizando una conmutación eficiente y minimizando las pérdidas de energía.

\begin{figure}[ht]
	\centering
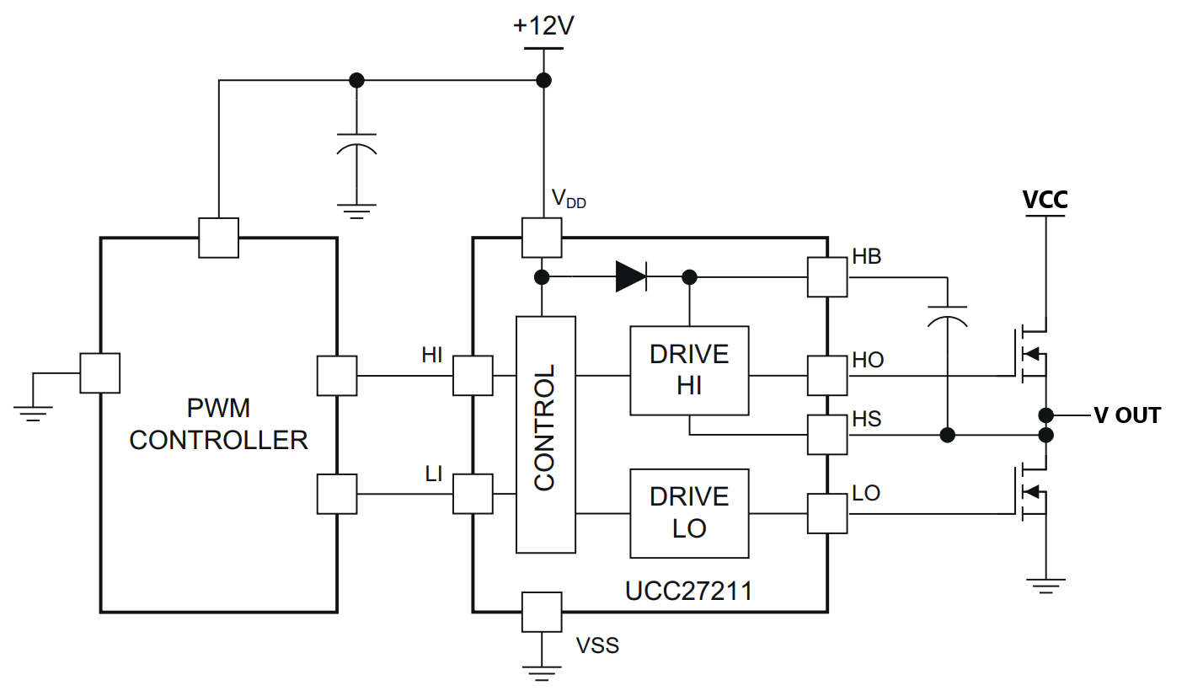
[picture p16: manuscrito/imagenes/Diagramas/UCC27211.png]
	
	\caption{Esquema UCC27211.}
	\label{UCC27211}
\end{figure}
\FloatBarrier

Se utilizó el controlador de puerta \textbf{UCC27211} de Texas Instruments, el cual es un driver de doble canal diseñado específicamente para controlar pares de MOSFETs y, como se puede ver en la figura \ref{UCC27211}, este tiene un esquema de conexiones bastante simple. Este dispositivo ofrece entradas de control independientes para los MOSFETs de alta (\texttt{H In}) y baja (\texttt{L In}), lo que permite un control preciso y flexible de cada transistor de potencia.

\begin{table}[ht]
	\centering
	\caption{Tabla de Lógica del UCC27211}
	\label{tab:device_logic}
	\begin{tabular}{|c|c|c|c|c|}
		\hline
		\textbf{H In} & \textbf{L In} & \textbf{H Out} & \textbf{L Out} & \textbf{V Out} \\ \hline
		L             & L             & L              & L              & Z              \\ \hline
		L             & H             & L              & H              & GND            \\ \hline
		H             & L             & H              & L              & VCC            \\ \hline
		H             & H             & H              & H              & Corto          \\ \hline
	\end{tabular}
\end{table}
\FloatBarrier

\newpage
Como se puede apreciar en la tabla \ref{tab:device_logic}, el UCC2711 no incorpora protección interna contra la conducción simultánea de ambos MOSFETs, conocido como \textbf{shoot-through}. Este fenómeno ocurre cuando ambos MOSFETs de una pierna se activan y conducen al mismo tiempo, generando un cortocircuito entre el suministro de voltaje y tierra. Para evitar esta situación, es importante agregar un tiempo entre la conmutación de las señales de entrada, conocido como \textbf{Dead-Time}, el cual se estima considerando los tiempos de conmutación del controlador de puerta junto con el tiempo de conmutación del mosfet.

\begin{figure}[ht]
	\centering
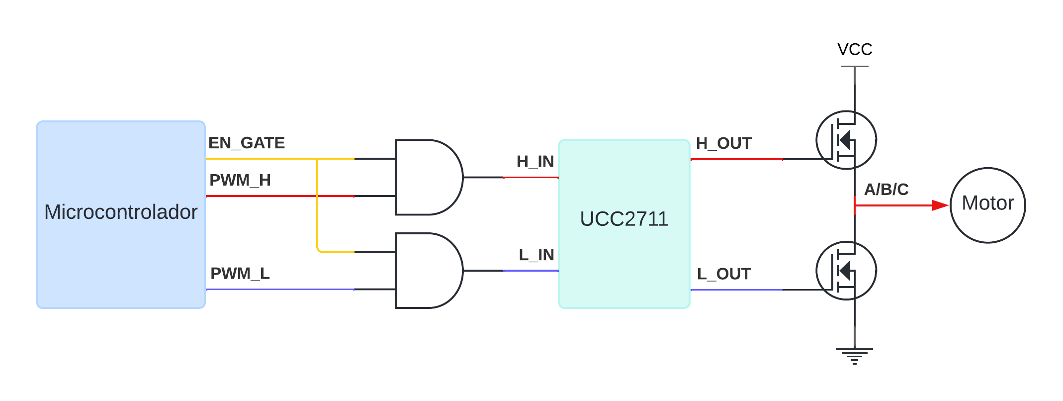
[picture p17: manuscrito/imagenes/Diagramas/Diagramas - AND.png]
	
	\caption{Esquema de control PWM con las compuertas AND.}
	\label{fig:control-pwm-and}
\end{figure}
\FloatBarrier

El UCC27211 no dispone de un pin para activar o desactivar el control de los mosfets. Por su parte, la única forma de desactivar el puente mosfet en su totalidad es llevar las señales de entrada alta (H In) y baja (L In) a un estado bajo (L). Además, el microcontrolador, al realizar esta acción, puede llegar a perder el control sobre el estado de las señales PWM y así generar por un breve momento un estado de doble activación de los mosfet. Para evitar esto, se agregaron externamente dos compuertas AND modelo SN74LVC1G08DBVR en cada señal PWM, como se puede ver en la figura \ref{fig:control-pwm-and}, con el fin de poder cortar las señales desde el microcontrolador de forma segura y así desactivar el puente mosfet. El comportamiento final con este agregado se puede ver en la tabla \ref{UCC27211_logic}.

\begin{table}[ht]
	\centering
	\caption{Tabla de Lógica del UCC27211 con AND}
	\label{UCC27211_logic}
	\begin{tabular}{|c|c|c|c|c|c|c|c|}
		\hline
		\textbf{EN GATE} & \textbf{PWM H} & \textbf{PWM L} & \textbf{H In} & \textbf{L In} & \textbf{H Out} & \textbf{L Out} & \textbf{V Out} \\
		\hline
		H                & L              & L              & L             & L             & L              & L              & Z              \\ \hline
		H                & L              & H              & L             & H             & L              & H              & GND            \\ \hline
		H                & H              & L              & H             & L             & H              & L              & VCC            \\ \hline
		H                & H              & H              & H             & H             & H              & H              & Corto          \\ \hline
		L                & X              & X              & L             & L             & L              & L              & Z              \\ \hline
	\end{tabular}
\end{table}
\FloatBarrier

\newpage
\subsection{Sensores de Corriente}

Para el sensor de corriente se optó por una configuración de resistencia shunt en la salida del puente mosfet, como se puede ver en la figura \ref{INA240}. Esta configuración aprovecha la caída de tensión provocada por la resistencia de valor conocido para poder calcular la corriente del circuito. Se utiliza un amplificador instrumental especializado en esta aplicación. En este caso, se utilizó el INA240A1, que tiene una ganancia de 20V/V y se le aplica un offset equivalente a la mitad del voltaje de referencia de 3.3V.

\begin{figure}[ht]
	\centering
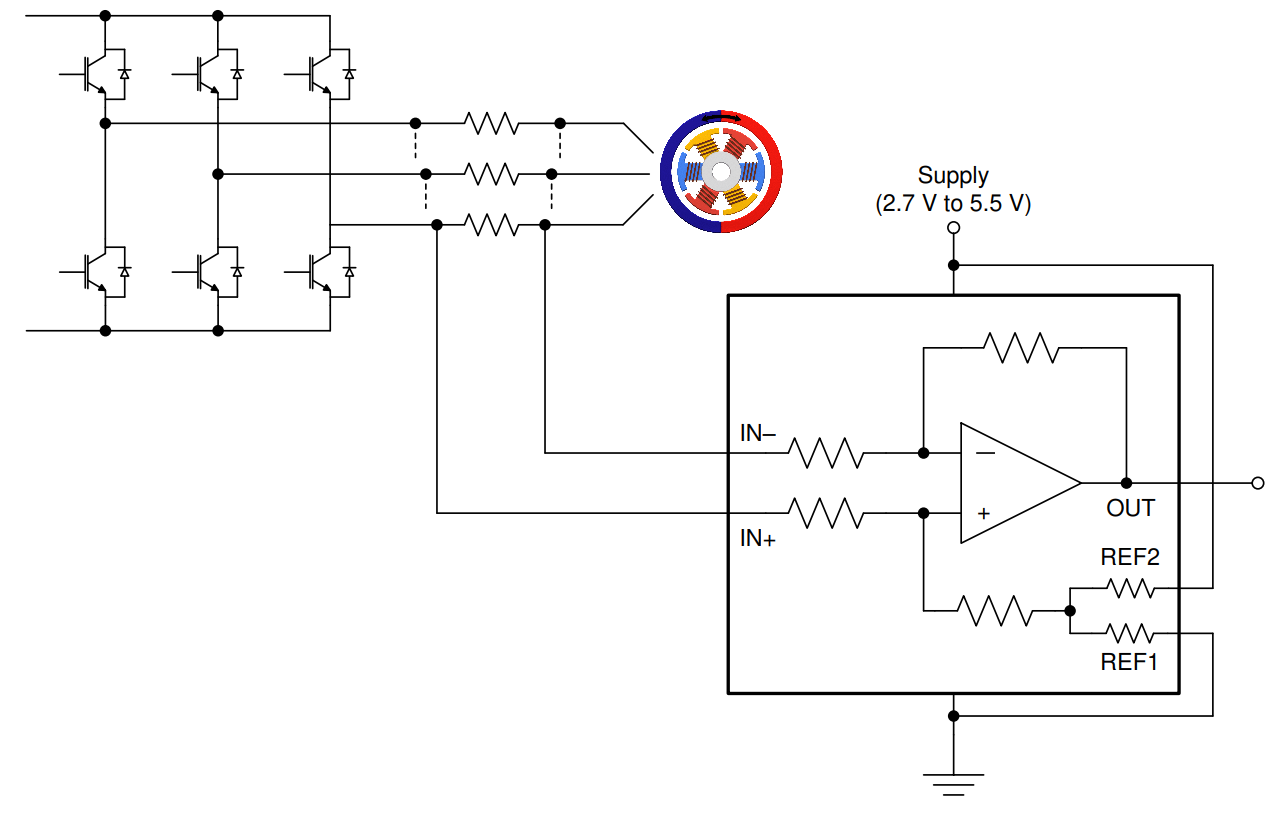
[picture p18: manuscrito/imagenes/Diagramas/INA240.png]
	
	\caption{Esquema INA240.}
	\label{INA240}
\end{figure}
\FloatBarrier

Para la resistencia shunt se utilizó una doble resistencia en paralelo, como se ve en la figura \ref{PCB_pierna_C}. La resistencia es de 1m$\Omega$ y 5W de disipación, lo que da una resistencia equivalente de 500$\mu\Omega$ y 10W de disipación. Para determinar la corriente máxima que puede pasar por la resistencia conociendo su valor en ohmios \( R \) y la potencia \( P \) en vatios, se puede calcular utilizando la siguiente fórmula:

\[
	I_{\text{max}} = \sqrt{\frac{P}{R}}
\]

Donde:
\begin{itemize}
	\item \( I_{\text{max}} \) es la corriente máxima,
	\item \( P \) es la potencia en vatios (W),
	\item \( R \) es el valor de la resistencia en ohmios ($\Omega$).
\end{itemize}

De esta forma, se determina que el máximo de corriente continua que puede circular por las resistencias es de 141.42A.

\newpage
\section{Implementación del puente MOSFET}
El diseño de la PCB está realizado en el software Eagle, ya que este entorno de diseño ofrece una interfaz amigable para el diseño de PCBs, además de una gran adaptabilidad según las necesidades del proyecto.

\begin{figure}[ht]
	\centering
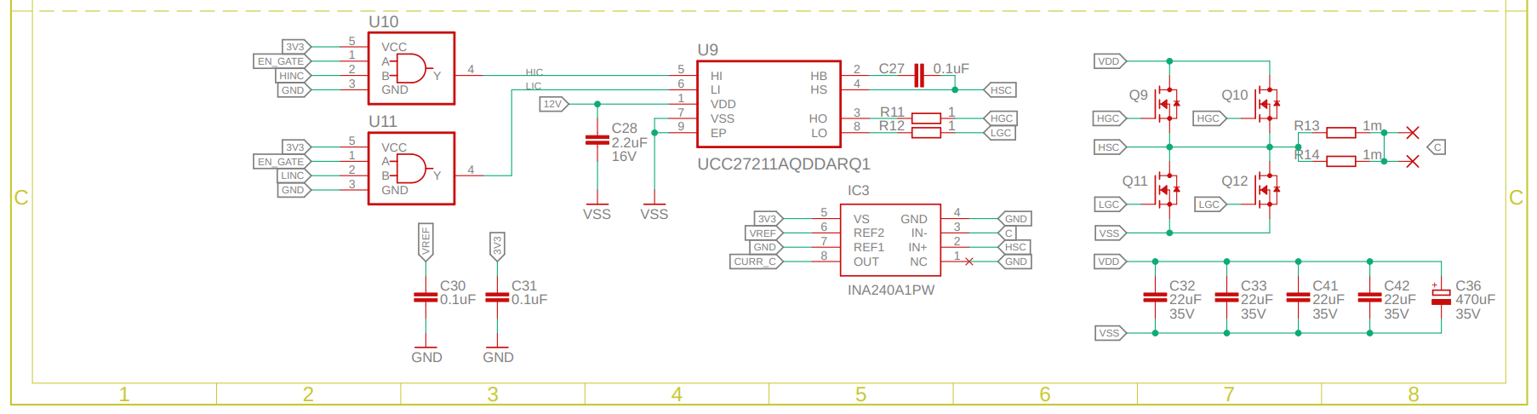
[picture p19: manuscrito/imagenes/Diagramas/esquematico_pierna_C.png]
	
	\caption{Esquemático de la pierna C del inversor.}
	\label{esquema_pierna_C}
\end{figure}
\FloatBarrier

En la Figura \ref{esquema_pierna_C} se presenta el esquemático de una de las piernas del inversor, específicamente la pierna C.  Como se puede apreciar, se conectaron condensadores de desacoplo de 100$\text{nF}$ en las entradas de alimentación de los diferentes componentes para mitigar el ruido proveniente de los reguladores de voltaje. Adicionalmente, se incorporó un regulador de voltaje de referencia de 3.3V, el cual no solo sirve como referencia para los ADC, sino que también se utiliza para el ajuste del offset en los amplificadores INA240.

\begin{figure}[ht]
	\centering
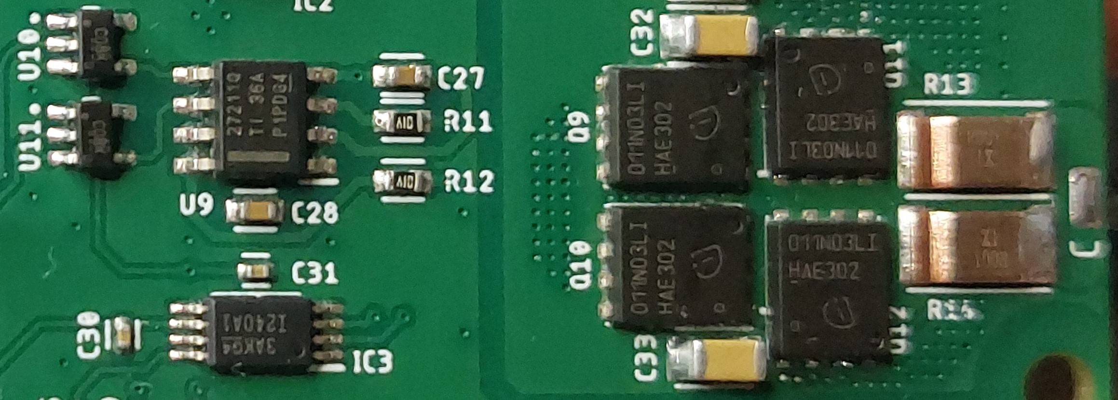
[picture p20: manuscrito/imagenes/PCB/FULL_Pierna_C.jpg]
	
	\caption{Pierna C del inversor.}
	\label{PCB_pierna_C}
\end{figure}
\FloatBarrier

La implementación física de la pierna C del inversor se muestra en la Figura \ref{PCB_pierna_C}.  Basado en las características del MOSFET, que soporta una corriente continua de 100 A, se determinó que utilizar solo dos MOSFETs por pierna sería insuficiente. Por lo tanto, se optó por una configuración de cuatro MOSFETs, con doble MOSFET en paralelo. De esta manera, como se observa en la figura,  se puede considerar una capacidad total de 200A continuos, despreciando las leves diferencias entre los MOSFETs del mismo modelo.

\begin{figure}[ht]
	\centering
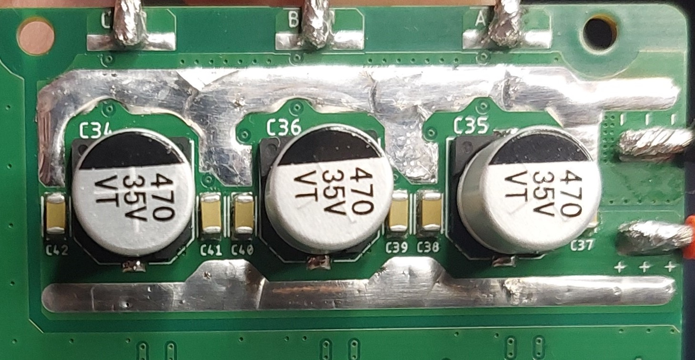
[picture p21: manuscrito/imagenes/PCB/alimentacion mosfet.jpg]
	
	\caption{Alimentación del Puente MOSFET.}
	\label{alimentacion}
\end{figure}
\FloatBarrier

En la Figura \ref{alimentacion}, que muestra la alimentación del puente MOSFET en el reverso de la PCB, se puede apreciar el estañado realizado en las pistas de alimentación de alta corriente correspondientes al puente MOSFET. Esta medida se implementó en respuesta a las altas exigencias de corriente demandadas por el motor.  Conjuntamente, se dispusieron varios capacitores electrolíticos de 470$\mu\text{F}$ y capacitores cerámicos de 22$\mu\text{F}$ estratégicamente posicionados para mitigar los picos de corriente y garantizar la estabilidad del sistema.

%Finalmente, la PCB fue fabricada a pedido por JLCPCB, eligiendo este proveedor por su plataforma intuitiva, que simplifica significativamente el proceso de producción.  Además, el diseño de la PCB consta de 6 capas, y JLCPCB ofrece costos competitivos para este tipo de configuraciones multicapa, convirtiéndolo en una opción económica y eficiente.

\newpage
\section{Observaciones y posibles mejoras}

Respecto al motor, se constató que presenta un elevado efecto de \emph{cogging torque}, lo cual incide de manera significativa en la estabilidad de la velocidad de giro. Existen sistemas comerciales que permiten calibrar y compensar este fenómeno. Sin embargo, en el presente proyecto no se incluyó dicha funcionalidad. Además, al someter el motor a cargas elevadas, se observó un notable incremento de temperatura, pudiendo alcanzar valores superiores al punto de deformación del material PLA utilizado en la fabricación del soporte para el \emph{encoder}. En consecuencia, se recomienda emplear materiales más resistentes al calor, como PETG o ABS, para la elaboración de este soporte.

En cuanto al puente MOSFET, el principal inconveniente radica en la activación simultánea de los transistores (conocida como “doble activación”), cuya causa podría ser una estimación inadecuada del \emph{deadtime} o posibles errores en las señales de control. Para mitigar este problema, se sugiere incorporar compuertas lógicas adicionales que eviten la conducción simultánea o, alternativamente, utilizar controladores de puerta con protecciones integradas, como el ISL6208 de Renesas, el cual ofrece protección activa contra la doble activación y elimina la necesidad de insertar un \emph{deadtime}. No obstante, es importante considerar que dicho controlador soporta menores voltajes de bus para los MOSFET.

Por último, se detectó que, en condiciones de carga extrema, las caídas de tensión en las pistas de alimentación de la PCB alcanzan niveles considerables, incluso cuando se aplica estañado. Para resolver esta situación, se recomienda aumentar el ancho de las pistas o soldar barras de cobre, con el fin de reducir su resistencia y mejorar la distribución de la corriente.

\newpage
\chapter{Firmware}
\section{Introducción}
Este capítulo busca documentar el desarrollo e implementación del firmware, partiendo de la revisión de los periféricos utilizados y la configuración de estos. Finalmente, se revisará a grandes rasgos el diseño e implementación del algoritmo para el control FOC.

\section{Microcontrolador y periféricos}
Se utilizó un microcontrolador de la serie H7 de STM32. Esta es la serie de alto rendimiento de STM32 que incorpora un núcleo ARM Cortex M7 con unidad de cálculo para punto flotante de doble precisión (FPU). El modelo específico es STM32H743VIT6. Su núcleo trabaja a 480MHz, tiene 1MB de memoria RAM y 2MB de memoria flash, ofreciendo así una potencia de cómputo y capacidad bastante elevada para un microcontrolador.

\begin{itemize}
	\item \textbf{Core}: Arm Cortex-M7 de 32bits a 480 MHz, FPU de doble precisión.
	\item \textbf{Memoria Flash}: 2 MB.
	\item \textbf{RAM}: 1 MB total (192 KB de RAM DTCM, 864 KB de SRAM).
	\item \textbf{Voltaje de operación}: 1.62 V - 3.6 V.
	\item \textbf{Empaquetado}: LQFP-100 (14 x 14 mm).
	\item \textbf{Entradas/Salidas}: 82 I/O.
	\item \textbf{Periféricos de comunicación}: USART, UART, SPI, CAN FD, USB, Ethernet.
	\item \textbf{Timers}: Hasta 22 timers (PWM, encoder, control de motores, etc.).
	\item \textbf{ADC}: 3x ADC tipo SAR de 16 bits (hasta 3.6 MSPS).
	\item \textbf{Programación y Depuración}: Interfaz SWD y JTAG.
\end{itemize}

Los periféricos en un microcontrolador son piezas de hardware especializados en una función que van integrados en el microcontrolador y permiten interactuar con el mundo exterior a través de sus señales eléctricas, ya sean entradas o salidas, digitales o análogas. En el ecosistema de STM32 existe la herramienta \textbf{STM32CubeMX}, que permite configurar todos los periféricos del microcontrolador desde una interfaz gráfica fácil de entender para posteriormente poder generar un código C que implemente todas las configuraciones en el microcontrolador utilizando las librerías HAL de STM32. De esta forma, \textbf{STM32CubeMX} genera un código base desde el que empezar a programar el firmware con todos los periféricos ya configurados.

\subsection{Configuración de Timers}
Los timers en los microcontroladores STM32 permiten contar eventos y controlar pines de salida según dichos eventos. Estos eventos pueden provenir del reloj interno o de señales externas. La familia STM32 ofrece gran flexibilidad para configurar modos de conteo, fuentes de reloj y funcionalidades específicas, como la generación de PWM o la captura de entrada.

\subsubsection{Timer 1}
El Timer 1, al ser de tipo \textbf{Advanced-control} de hasta 16 bits, está especialmente diseñado para la generación de señales PWM complementarias con inserción de \emph{dead time}, lo que facilita el control de puentes MOSFET. Se configura en modo \emph{center-aligned} (cuenta ascendente y descendente), permitiendo tener salidas PWM adecuadas para su uso con el SVM.

\begin{table}[h!]
	\centering
	\begin{tabular}{| l | l |}
		\hline
		\textbf{Parámetro en CubeMX}         & \textbf{Valor}           \\
		\hline
		Clock Source                         & Internal Clock (240 MHz) \\
		Counter Mode                         & Center Aligned mode 3    \\
		Counter Period (16 bits)             & 5000                     \\
		Trigger Event Selection TRGO         & Update Event             \\
		Dead Time                            & 50                       \\
		\hline
		Channel 1                            & PWM Generation CH1 CH1N  \\
		PWM Generation Channel 1 and 1N Mode & PWM mode 1               \\
		\hline
		Channel 2                            & PWM Generation CH2 CH2N  \\
		PWM Generation Channel 2 and 2N Mode & PWM mode 1               \\
		\hline
		Channel 3                            & PWM Generation CH3 CH3N  \\
		PWM Generation Channel 3 and 3N Mode & PWM mode 1               \\
		\hline
	\end{tabular}
	\caption{Configuración del Timer 1 en CubeMX.}
	\label{TIM1_config}
\end{table}
\FloatBarrier

Dado que el reloj base es de 240 MHz y el \texttt{Counter Period} se establece en 5000, se obtiene un evento de desborde a 48 kHz (\(\frac{240\text{ MHz}}{5000} = 48\text{ kHz}\)) (El desborde es cuando el contador llega a su valor mínimo o máximo). En modo \emph{center-aligned}, cada ciclo completo de PWM comprende una fase ascendente y otra descendente, por lo que el PWM resultante es de 24 kHz. Además, las interrupciones del Timer 1 se generan en cada suceso de desborde, por lo que se dispone de una rutina de interrupción a 48 kHz para efectuar los cálculos y actualizaciones del lazo de control.

\subsubsection{Timer 3}
El Timer 3 es un timer de uso general de 16 bits, está configurado en \textbf{modo encoder}, que permite contar los pulsos de un \emph{encoder} incremental sin intervención directa del firmware. De este modo, el microcontrolador registra por hardware los cambios de las fases A y B, en modo de conteo por 4 (X4). Se configura un \emph{input filter} para evitar pulsos espurios debidos al ruido, y se asigna un \texttt{Counter Period} de 65535 (el máximo para 16 bits), aunque este valor, al corresponder solo a unos pocos giros del motor, hace necesario implementar una gestión del desborde del timer.

\subsubsection{Timer 2}
El Timer 2 es un timer de uso general de 32 bits, se utiliza para adquirir mediciones precisas de tiempo relacionadas con la operación del encoder y la sincronización global del sistema. En CubeMX, se configura con reloj interno (\emph{Internal Clock} de 240 MHz) y se opera en modo \emph{Up} con un \texttt{Counter Period} de 4294967295 (valor máximo de 32 bits). A continuación, se describen las conexiones de cada canal:

\begin{table}[h!]
	\centering
	\begin{tabular}{| l | l |}
		\hline
		\textbf{Parámetro en CubeMX} & \textbf{Valor}                 \\
		\hline
		Trigger Source               & ITR0 (Timer 1 Trigger Out)     \\
		Clock Source                 & Internal Clock (240 MHz)       \\
		Counter Mode                 & Up                             \\
		Counter Period (32 bits)     & 4294967295                     \\
		\hline
		Channel 1                    & Input Capture triggered by TRC \\
		\hline
		Channel 2                    & Input Capture direct mode      \\
		Polarity                     & Both Edges                     \\
		\hline
		Channel 3                    & Input Capture direct mode      \\
		Polarity                     & Rising Edge                    \\
		\hline
	\end{tabular}
	\caption{Configuración del Timer 2 en CubeMX.}
	\label{TIM2_config}
\end{table}
\FloatBarrier

\begin{itemize}
	\item \textbf{Canal 1 conectado al Trigger Out del Timer 1:} Sirve para registrar con exactitud el instante en que el Timer 1 genera un evento de disparo. También se utiliza para gestionar el desborde del Timer 2 vía software, aumentando el rango de medición de tiempo (al ser de 32 bits, por defecto podría tardar unos 17,9 segundos en desbordar).

	\item \textbf{Canal 2 conectado a la salida \emph{XOR} de las señales A y B del encoder:} Genera un flanco de subida o bajada en cada pulso del encoder, permitiendo medir, mediante \emph{Input Capture}, el tiempo exacto entre pulsos y así refinar el cálculo de velocidad. Este método aporta mayor exactitud de tiempo que limitarse únicamente al uso del periodo de las interrupciones.

	\item \textbf{Canal 3 conectado a la señal \emph{Index} del encoder:} Aunque no se usa actualmente para una función concreta, permite determinar con precisión el momento en que dicha señal es \href{https://www.youtube.com/watch?v=FavUpD_IjVY}{activada}, facilitando futuras expansiones en la detección de referencias de giro.
\end{itemize}

\subsection{Configuración de los ADC y su integración con Timers y DMA} En los microcontroladores STM32, los conversores analógico-digital (ADC) se encargan de transformar voltajes analógicos en valores digitales dentro de un rango específico. En la serie H7, cada ADC ofrece una resolución de 16 bits y puede operar en dos modos principales:

\begin{itemize}
	\item \textbf{Conversión regular:} Permite leer hasta 16 canales en una secuencia programable. Se puede combinar con el módulo DMA (Acceso Directo a Memoria) para transferir los valores de conversión directamente a la memoria RAM sin necesidad de intervención del procesador, optimizando así el rendimiento.
	\item \textbf{Conversión inyectada:} Interrumpe la conversión regular para realizar, de forma prioritaria, hasta 4 mediciones de canales configurables. Este modo resulta útil cuando se requiere sincronizar lecturas en instantes precisos o realizar mediciones críticas con mínima latencia.
\end{itemize}

\textbf{DMA (Acceso Directo a Memoria):} El DMA es un módulo que permite trasladar datos entre periféricos y la memoria sin intervención de la CPU. De esta manera, mientras el ADC realiza sus mediciones, el DMA copia automáticamente los resultados a la RAM, liberando al núcleo del microcontrolador de dichas tareas y mejorando la eficiencia general del sistema.

\textbf{ADC 1:} El ADC 1 se encarga de la medición de las corrientes de fase, provenientes de los amplificadores operacionales que acondicionan las resistencias \emph{shunt}. Para sincronizar estas mediciones con las interrupciones del sistema y asegurar que las lecturas estén disponibles a tiempo, se utiliza el \textbf{modo inyectado} del ADC, asociado a un disparo (\emph{trigger}) generado por el Timer 15.

\textbf{Timer 15:} El Timer 15 está configurado como esclavo del Timer 1 y emplea su \emph{Channel 1} en modo de comparación, sin generar salida directa, pero conectado al (\emph{trigger out}). De esta forma, se produce un pulso de sincronización con un pequeño desfase respecto a cuando se ejecute la interrupción del Timer 1. Este pulso activa la lectura inyectada en el ADC 1. Así, los resultados de las mediciones están listos en los registros del ADC cuando se ejecuta la rutina de interrupción.

\textbf{ADC 3:} El ADC 3 se utiliza para monitorear el voltaje de bus (por ejemplo, el suministro proveniente de la batería o la fuente principal). Dado que esta lectura no requiere una sincronización tan estricta, se configura en \textbf{modo regular}, habilitando conversiones continuas. Adicionalmente, se activa el módulo DMA para transferir los resultados al área de memoria en RAM, evitando sobrecargar la CPU con lecturas repetitivas.

\textbf{ADC 2:} Por último, el ADC 2 está destinado a la lectura de señales analógicas utilizadas, en este caso, conectados a potenciómetros utilizados para el control de los setpoints en los controladores. Al igual que en el ADC 3, se configura en \textbf{modo regular} con conversiones continuas, y se emplea el DMA para automatizar la transferencia de los datos a memoria. Con esta configuración, se pueden atender varios canales analógicos (por ejemplo, múltiples potenciómetros) sin que el procesador se vea afectado por interrupciones frecuentes.

\section{Estructura del Firmware}

Para la gestión del control del motor, el firmware se estructura en torno a dos líneas de ejecución principales que operan de forma pseudo-paralela. Esta arquitectura se basa en la utilización de la \href{https://www.youtube.com/watch?v=poa_QBvtIBA}{interrupción} del Timer 1 para la ejecución de las tareas críticas de control, generando lo que se puede conceptualizar como un \emph{``doble hilo de ejecución''}.  Esta estructura permite mantener una ejecución continua en la función principal (\texttt{main()}) mientras se ejecutan las rutinas de control de motor de alta prioridad en la interrupción.

\begin{figure}[ht]
	\centering
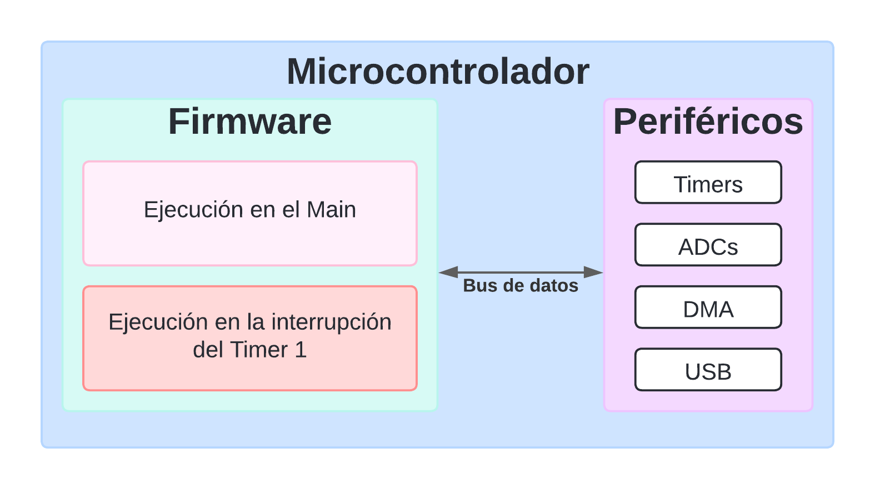
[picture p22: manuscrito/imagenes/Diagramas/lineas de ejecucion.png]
	
	\caption{Bosquejo de la estructura general del firmware en el microcontrolador.}
	\label{firmware_microcontrolador}
\end{figure}
\FloatBarrier

La Figura \ref{firmware_microcontrolador} ilustra esta estructura, mostrando cómo el firmware se compone de estas dos líneas de ejecución que interactúan con los periféricos del microcontrolador para llevar a cabo las funciones de control del motor y la interacción con el sistema.

\subsection{Ejecución en Main}

La ejecución en \texttt{main} inicia con una etapa de \textbf{configuración del sistema}, en la cual se inicializan los periféricos (por ejemplo, los \textbf{ADCs} y los \textbf{timers}). Posteriormente, se ejecuta una \textbf{secuencia de arranque del motor}, que incluye la calibración a cero en los sensores de corriente, el proceso de \emph{homing} y el ajuste del \emph{offset} en el encoder.

\begin{figure}[ht]
	\centering
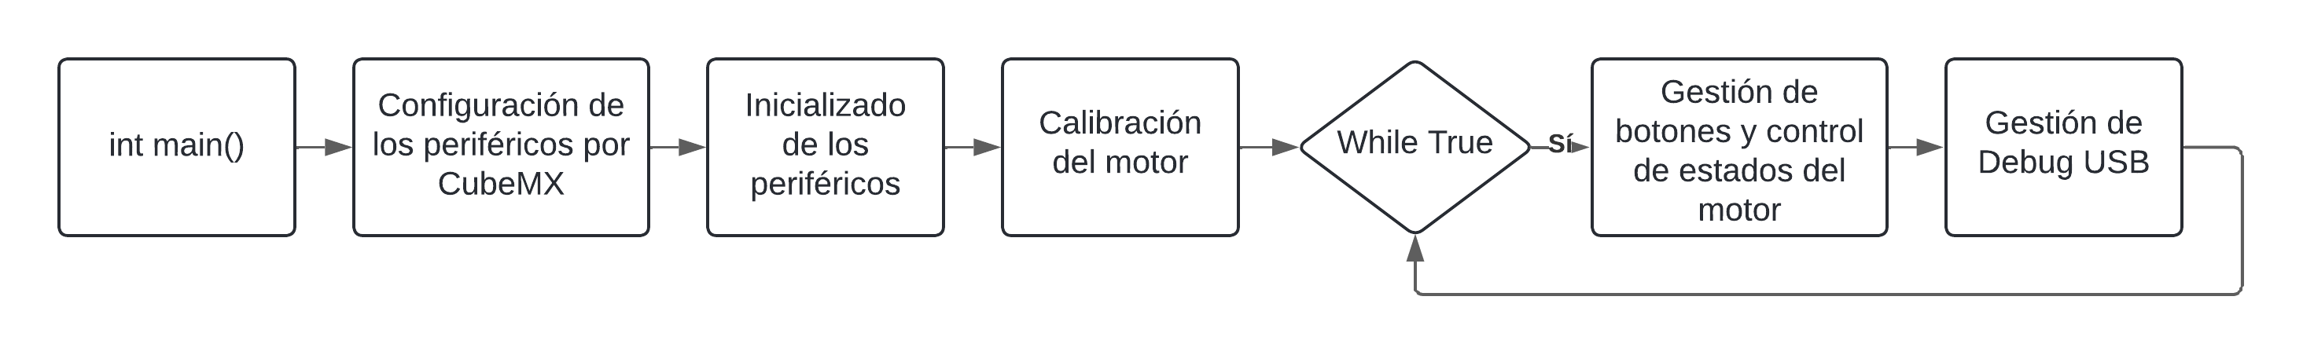
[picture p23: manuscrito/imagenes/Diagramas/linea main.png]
	
	\caption{Diagrama de flujo de las tareas principales en la línea de ejecución \texttt{main()}.}
	\label{fig:linea_ejecucion_main}
\end{figure}
\FloatBarrier

La Figura \ref{fig:linea_ejecucion_main} presenta un diagrama de flujo resumido de las tareas principales que se ejecutan en la función \texttt{main()}. Tras la inicialización, el programa entra en un bucle \texttt{while(true)}, que constituye el \emph{``bucle principal''} del sistema. En este bucle se gestiona la interacción con el usuario a través de pulsadores, se controla el estado del motor y se maneja la comunicación a través del puerto USB para el envío de datos y funcionalidades de depuración.

\subsection{Ejecución en Interrupción}

la figura \ref{fig:linea_ejecucion_interrupcion} muestra a grandes rasgos la \textbf{rutina de interrupción} \href{https://www.youtube.com/watch?v=RJX_jYm8T84}{asociada} al \texttt{Timer 1} maneja lo relacionado al \textbf{lazo de control del motor} mostrado en la figura \ref{fig:foc_transform}. Su funcionamiento comienza con la obtención de datos provenientes los timers para las medisiones de tiempo y posicion, asi como la abstención de los datos medidos por los ADCs que son almacenados en la memoria RAM por el DMA, estos datos son procesados y normalizados para ser aplicados en las \textbf{transformadas de Clarke y Park} y asi obtener las variables de estado del motor.

\begin{figure}[ht]
	\centering
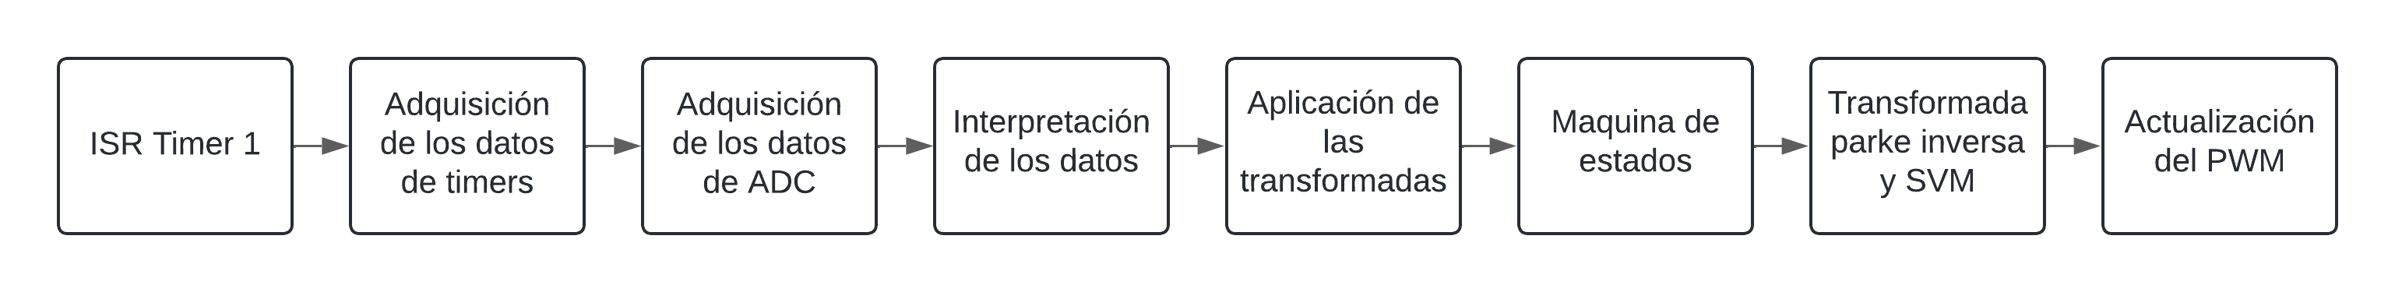
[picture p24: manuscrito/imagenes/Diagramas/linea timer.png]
	
	\caption{Diagrama de flujo de las tareas principales en la línea de ejecución de la interrupción.}
	\label{fig:linea_ejecucion_interrupcion}
\end{figure}
\FloatBarrier

Se utilizo una \textbf{máquina de estados} para la ejecucion de diferentes tareas, esta es controlada directamente desde la ejecucion main y tiene la capacidad de concadenar varias acciones, de esta forma es capas de realizar las calibraciones del sistema, hacer pruebas con modos alternativos de control o ejecutar el laso de control de velocidad. Finalmente, los valores de salida de se usan para calcular la transformada inversa de Park y consecutivamente el \textbf{SVM} para obtener los valores para los PWM.

\newpage
\section{Observaciones y posibles mejoras}

Durante el desarrollo del firmware, se identificó una consideración relevante para el sistema: la familia de microcontroladores STM32H7 presenta un error de arquitectura que complica el uso del DMA en condiciones normales. Este problema se debe a la división de la memoria RAM en regiones diferentes, lo que obliga a especificar la región de memoria deseada para cada variable o registro objetivo del DMA.

En lo que respecta al entorno de desarrollo, fue necesario emplear una máquina virtual con Ubuntu a través de WSL (Windows Subsystem for Linux) para compilar y escribir el código fuente utilizando VSCode, dado que la instalación del entorno en Windows no ofreció los resultados esperados.

En cuanto al lenguaje de programación, aunque el firmware se implementó en C, se observó que los microcontroladores STM32 también pueden ser programados en C++ con ligeras modificaciones al archivo \texttt{main}, lo que podría simplificar la gestión de recursos y la modularidad del código al permitir el uso de objetos.

Por último, para organizar de manera eficaz las subtareas y propiciar una mayor escalabilidad, se sugiere utilizar FreeRTOS. Este sistema operativo de tiempo real para microcontroladores puede integrarse directamente desde STM32CubeMX, proporcionando una estructura más robusta para el manejo de hilos de ejecución (threads) y facilitando la segmentación adecuada de las funciones que componen el firmware.

\newpage
\chapter{Validación}
Para las validaciones, se realizó una adquisición de datos, donde estos se recopilan ciclo a ciclo en la memoria RAM del microcontrolador para su posterior envío de forma asincrónica por el puerto USB, como se muestra en la figura \ref{flujo_debug}. Los datos son recibidos en una computadora a través de un código en Python, donde se almacenan en archivos CSV. Esta recopilación de información se realiza al final de cada ejecución de la interrupción del sistema, la cual se ejecuta a una frecuencia de 48 kHz. Debido a las limitaciones de memoria, la recopilación de datos solo puede llevarse a cabo durante un período de aproximadamente 100 ms, hasta alcanzar la capacidad máxima de la memoria.

\begin{figure}[ht]
	\centering
	
	\caption{Diagrama de flujo adquisición de datos.}
	\label{flujo_debug}
\end{figure}
\FloatBarrier

\section{Validación de la adquisición y transformación de las mediciones de corriente}

\subsection{Validación de las mediciones de corriente}
Se validarán las mediciones de corriente adquiridas desde el microcontrolador.

\begin{figure}[ht]
	\centering
	
	\caption{Corrientes ideales en un sistema trifásico equilibrado.}
	\label{corrientes_ABC_ideal}
\end{figure}
\FloatBarrier

En la figura \ref{corrientes_ABC_ideal} se representan las señales ideales de un sistema trifásico equilibrado, con las tres corrientes de fase $I_a$, $I_b$ e $I_c$, cada una de ellas con una forma senoidal pura y un desfase de $120^\circ$ entre sí.

\begin{figure}[ht]
	\centering
	
	\caption{Corrientes medidas en el sistema trifásico.}
	\label{corrientes_ABC}
\end{figure}
\FloatBarrier

En la figura \ref{corrientes_ABC} se pueden apreciar las corrientes de fase, las cuales presentan una cantidad significativa de ruido, aun cuando internamente pasan por un filtro complementario con una frecuencia de corte $f_W=12000Hz$. No obstante, mantienen un comportamiento sinusoidal con el desfase de $120^\circ$ entre señales, como es característico de un sistema trifásico equilibrado. Sin embargo, la cantidad de ruido podría indicar que sería necesario disminuir la frecuencia de corte en el filtro complementario o agregar un filtro pasivo en el circuito.

\newpage
\subsection{Validación de la transformada de Clarke}

Se validarán los resultados a la salida de la transformada de Clarke en el microcontrolador.

\begin{figure}[ht]
	\centering
	
	\caption{Corrientes ideales en el plano $\alpha\beta$.}
	\label{corrientes_alpha_beta_ideal}
\end{figure}
\FloatBarrier

En la figura \ref{corrientes_alpha_beta_ideal} se representan las corrientes ideales en el plano $\alpha\beta$, con las formas senoidales puras con un desfase de $90^\circ$ entre sí.

\begin{figure}[ht]
	\centering
	
	\caption{Corrientes medidas en el plano $\alpha\beta$.}
	\label{corrientes_alpha_beta}
\end{figure}
\FloatBarrier

En la figura \ref{corrientes_alpha_beta} se puede apreciar cómo las corrientes $\alpha\beta$ reflejan el ruido presente en las mediciones de los sensores de corriente, pero mantienen el comportamiento esperado a la salida de la transformada de Clarke, con las dos señales sinusoidales con un desfase de $90^\circ$ entre señales, como es característico.

\newpage
\subsection{Validación de la transformada de Park}

Se validarán los resultados a la salida de la transformada de Park en el microcontrolador.

\begin{figure}[ht]
	\centering
	
	\caption{Corrientes ideales en el plano $dq$.}
	\label{corrientes_dq_ideal}
\end{figure}
\FloatBarrier

En la figura \ref{corrientes_dq_ideal} se representan las corrientes ideales en el plano $dq$, donde lo ideal es que la corriente directa tenga un valor de cero, para mantener la eficiencia del sistema, mientras que solo la corriente de cuadratura tiene un valor distinto de cero.

\begin{figure}[ht]
	\centering
	
	\caption{Corrientes medidas en el plano $dq$.}
	\label{corrientes_dq}
\end{figure}
\FloatBarrier

En la figura \ref{corrientes_dq} se puede apreciar cómo las corrientes $dq$ presentan una menor cantidad de ruido gracias a que su filtro complementario está ajustado para una frecuencia de corte de $f_W=800Hz$. Aunque igualmente presentan ciertas deformaciones e inestabilidad con un patrón aparentemente constante, en términos generales, mantienen aproximadamente el comportamiento esperado a la salida de la transformada de Park.

\newpage
\section{Validación de los Controladores PI}
En esta validación se busca comprobar si los controladores PI de velocidad y corriente son capaces de mantener sus setpoints. Las pruebas se realizaron de forma estática, aplicando una carga ligera sobre el motor y capturando datos durante este proceso.

\subsection{Validación del controlador de velocidad}
Para la validación, se aplicó un setpoint de 116.8 RPM utilizando uno de los potenciómetros disponibles.

\begin{figure}[ht]
	\centering
	
	\caption{Velocidad medida por el encoder y setpoint de velocidad.}
	\label{velocidad_encoder}
\end{figure}
\FloatBarrier

En la Figura \ref{velocidad_encoder}, se observa que la velocidad medida por el encoder sigue adecuadamente el setpoint establecido de 116.8 RPM. A pesar de ligeras oscilaciones, el controlador de velocidad mantiene el régimen deseado, \href{https://www.youtube.com/watch?v=B8VR5mQcgjI}{demostrando} su capacidad para alcanzar y mantener el setpoint bajo condiciones de carga estática.

\newpage
\subsection{Validación del controlador de corriente}

\begin{figure}[ht]
	\centering
	
	\caption{Corrientes medidas en el plano $dq$.}
	\label{cont_corrientes_dq}
\end{figure}
\FloatBarrier

Como se muestra en la Figura \ref{cont_corrientes_dq}, las corrientes en el plano $dq$ indican que el controlador de corriente logra mantener la corriente de cuadratura ($I_q$) cercana al valor de referencia proporcionado por el controlador de velocidad, mientras que la corriente directa ($I_d$) se mantiene próxima a cero. Esto evidencia que el controlador de corriente regula eficazmente las corrientes según los setpoints establecidos.

\begin{figure}[ht]
	\centering
	
	\caption{Voltajes en el plano $dq$.}
	\label{voltajes_dq}
\end{figure}
\FloatBarrier

Además, la Figura \ref{voltajes_dq} presenta los voltajes en el plano $dq$, donde se aprecia que las tensiones generadas están dentro de los valores esperados para mantener las corrientes deseadas. Esto corrobora que el controlador de corriente responde adecuadamente a las demandas del sistema, contribuyendo al correcto desempeño del motor bajo condiciones de carga.

\newpage
\section{Validación señales del SVM}

Para validar el funcionamiento del modulador por vector espacial (SVM), se realizaron pruebas virtuales aplicando diferentes valores de tensión de referencia $V_{\text{ref}}$ al SVM para observar su comportamiento. Durante estas pruebas, se utilizó un analizador lógico para capturar las señales PWM generadas por el microcontrolador. En la captura presentada, se aisló un ciclo completo del PWM donde se puede apreciar de forma clara la secuencia de activación correspondiente al sector 1.

\begin{figure}[ht]
	\centering
	
	\caption{Señales del timer.}
	\label{señal_timer}
\end{figure}
\FloatBarrier

En la Figura \ref{señal_timer}, se observan las señales PWM correspondientes a las tres fases generadas por el microcontrolador. La secuencia de activación muestra que el SVM implementado sigue correctamente el patrón teórico esperado para el sector 1, evidenciando una conmutación precisa y sincronizada de los transistores del inversor. Esto confirma que el SVM está modulando adecuadamente las señales PWM para generar los vectores de tensión requeridos.

\newpage
\chapter*{Comentarios y Conclusiones}
\addcontentsline{toc}{chapter}{Comentarios y Conclusiones}

\paragraph{Respecto al objetivo: ``Estudiar los principios del Control de Campo Orientado (FOC) y la modulación de espacio vectorial (SVM) para aplicarlos en el diseño del controlador''} Se concluye que la base teórica relacionada con el funcionamiento de los motores \textit{brushless} y el Control de Campo Orientado (FOC) abarca un espectro más amplio que el revisado en este proyecto. Las transformadas de Clarke y Park simplifican el análisis e implementación del sistema, aunque sería posible profundizar en metodologías de control FOC directo.

\paragraph{Respecto al objetivo: ``Diseñar el hardware para el controlador FOC, con los componentes mínimos necesarios para validar el funcionamiento''} Se concluye que el uso de \emph{Autodesk Eagle} facilita de manera significativa el proceso de diseño tanto del esquemático como de la placa de circuito impreso (PCB). La disponibilidad de recursos y librerías en línea agiliza la búsqueda de los componentes específicos y su integración, garantizando la coherencia entre el símbolo de cada dispositivo y su respectivo \emph{footprint}. Además, la compatibilidad con los servicios de \emph{JLCPCB}, que proporciona reglas de diseño y formatos de archivos \emph{Gerber} precisos, contribuyó a la fabricación eficiente y libre de inconvenientes de la placa.

\paragraph{Respecto al objetivo: ``Configurar y programar el microcontrolador para el algoritmo FOC, utilizando las librerías HAL de STM32''} Se concluye que la utilización de \emph{STM32CubeMX} reduce de forma notable la complejidad inicial de configuración de los periféricos, puesto que automatiza gran parte del proceso y evita lidiar directamente con registros de bajo nivel y los usos avanzados de la biblioteca HAL. No obstante, el elevado número de módulos disponibles en la familia STM32H7 y la gran variedad de parámetros de configuración requirieron una curva de aprendizaje considerable para conseguir un ajuste óptimo. A pesar de ello, la configuración final aprovecha de manera significativa las prestaciones del microcontrolador.

\paragraph{Respecto al objetivo: ``Validar el funcionamiento del controlador y proponer posibles mejoras para su aplicación en robótica competitiva''} Se concluye que el controlador desarrollado exhibe un desempeño estable en condiciones normales de operación. Sin embargo, las pruebas evidenciaron dificultades cuando se exige al sistema con aceleraciones bruscas o cambios de dirección repentinos. Además, aunque las compuertas AND permiten deshabilitar con seguridad el puente MOSFET ante posibles fallas, persiste el inconveniente de doble activación (\emph{shoot-through}) en determinadas circunstancias, lo que puede comprometer la integridad del prototipo. Dichas observaciones confirman la necesidad de perfeccionar tanto el hardware como el firmware para afrontar escenarios de carga extrema.

\paragraph{Respecto al objetivo principal: ``Implementar un controlador de tipo FOC para motores \textit{brushless} con encoder, utilizando un microcontrolador STM32, que sirva de base para un driver especializado en la robótica competitiva''} Se concluye que el controlador constituye una solución \href{https://www.youtube.com/watch?v=XnAQtDEaI2I}{funcional} para requerimientos estándar y cumple con la finalidad de servir como base para un \emph{driver} especializado en robótica competitiva. A lo largo del documento, se sugieren mejoras potenciales en ambas vertientes, hardware y firmware, que podrían optimizar el comportamiento del sistema en condiciones extremas, habituales en competencias de robótica. Adicionalmente, el uso de la familia STM32, en particular de la serie H7, ofreció un rendimiento notable, aun considerando ciertas dificultades de arquitectura que surgieron durante la fase de desarrollo. En consecuencia, se confirma la versatilidad de estos dispositivos para aplicaciones de alto desempeño y se resalta su amplio margen de crecimiento en futuros desarrollos.

\section*{Trabajos Futuros}
\addcontentsline{toc}{chapter}{Trabajos Futuros}
\begin{itemize}
	\item \textbf{Refinar la gestión del \emph{deadtime}:} Emplear controladores de puerta con protecciones integradas o añadir lógica adicional para prevenir la doble activación (\emph{shoot-through}) y preservar la confiabilidad del puente MOSFET.

	\item \textbf{Ampliar la robustez en el hardware:} Aumentar el ancho de las pistas o soldar barras de cobre en la PCB para soportar mejor los picos de corriente, junto con el uso de materiales termorresistentes (PETG o ABS) en piezas críticas que tengan contacto directo con el motor.

	\item \textbf{Optimizar la ejecución del firmware:} Migrar el código a C++ e integrar FreeRTOS para aprovechar la programación orientada a objetos y el manejo de hilos, facilitando la escalabilidad y la organización de tareas concurrentes.

	\item \textbf{Mejorar el filtrado de la señal de corriente:} Reducir la frecuencia de corte del filtro o añadir etapas analógicas pasivas para minimizar el ruido en las mediciones, incrementando así la precisión en el lazo de control.

	\item \textbf{Aumentar la versatilidad del sistema:} Explorar el soporte para un segundo motor y ampliar la capacidad de adquisición de datos, permitiendo el desarrollo de múltiples ejes de control para aplicaciones robóticas de mayor complejidad.

	\item \textbf{Incorporar compensaciones de \emph{cogging torque}:} Implementar algoritmos de calibración y compensación que disminuyan la vibración producida por el entrehierro, optimizando así la estabilidad de velocidad y el rendimiento general del motor.
\end{itemize}

\textbf{Link al repositorio Github: \url{https://github.com/eziron/driver_FOC}}

\newpage
\addcontentsline{toc}{chapter}{Bibliografía}
\printbibliography

\href{https://www.youtube.com/watch?v=2yJgwwDcgV8}{\phantom{ASDF--------------------ASDF}}

%\newpage
%\addcontentsline{toc}{chapter}{Anexos}

%\newpage
%\chapter*{Anexo: Pinout del Microcontrolador}
%\addcontentsline{toc}{section}{Anexo: Pinout del Microcontrolado}

%\begin{figure}[ht]
%	\centering
%	\includegraphics[width=\textwidth]{anexos/pinout.png}
%\end{figure}
%\FloatBarrier

%\newpage
%\chapter*{Anexo: Configuración RAM}
%\addcontentsline{toc}{section}{Anexo: Configuración RAM}

%\begin{figure}[ht]
%	\centering
%	\includegraphics[width=\textwidth]{anexos/dominios RAM.png}
%\end{figure}
%\FloatBarrier

%\newpage
%\addcontentsline{toc}{section}{Anexo: Configuración Relojes}
%\includepdf[pages=-]{anexos/relojes.pdf}

\end{document}

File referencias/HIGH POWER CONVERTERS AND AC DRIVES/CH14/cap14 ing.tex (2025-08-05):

\documentclass[letterpaper,12pt]{article}
\usepackage[utf8]{inputenc}
\usepackage[english]{babel}
\usepackage{graphicx}
\usepackage{amsmath}
\usepackage{amssymb}
\usepackage[margin=0.75in]{geometry}
\usepackage{chngcntr}
\usepackage{caption}
\usepackage{fancyhdr}
\usepackage{placeins}

% Adjust the header height
\setlength{\headheight}{14.5pt}
\addtolength{\topmargin}{2.5pt}
\setlength{\parskip}{1em}

% Configure section and subsection numbering
\renewcommand{\thesection}{14.\arabic{section}}
\renewcommand{\thesubsection}{14.\arabic{section}.\arabic{subsection}}

% Redefine figure counter
\captionsetup[figure]{labelformat=empty} % Avoid automatic numbering
\captionsetup[table]{labelformat=empty} % Avoid automatic numbering

% Configure fancyhdr
\pagestyle{fancy}
\fancyhf{}
\fancyhead[L]{Chapter 14}
\fancyhead[R]{\thepage}
\fancyfoot[C]{}

\title{Advanced Drive Control Schemes}
\author{}
\date{}

\begin{document}

\maketitle
\thispagestyle{fancy} % Apply fancyhdr style to the first page

\section{Introduction}

Two advanced control schemes, field-oriented control (FOC) and direct torque control (DTC), have become the industrial standards in high-power medium-voltage (MV) drives. This is in view of the following: (a) The control schemes offer superior dynamic performance; (b) their algorithms can be efficiently implemented in real time by digital processors; and (c) the cost difference between the digital implementations of advanced and low-performance control schemes is minimal.

This chapter focuses on FOC and DTC schemes for induction motor drives. It starts with an introduction to reference frame transformation, followed by dynamic models of the induction motor. Various field-oriented control schemes for the voltage and current source drives are presented. The emphasis is on the rotor flux oriented control scheme due to its simplicity and wide acceptance in the MV drives. The direct torque control is also elaborated. Important concepts are illustrated with computer simulations and experiments. The chapter ends with a comparison between the FOC and DTC schemes.

\section{Reference Frame Transformation}

The use of reference frame theory can simplify the analysis of electric machines and also provide a powerful tool for the digital implementation of sophisticated control schemes for ac drives. A number of reference frames have been proposed over the years [1], of which the stationary and synchronous reference frames are most commonly used. The transformation of variables between the two frames is presented below.

\subsection{abc/dq Frame Transformation}

The transformation of the three-phase (abc-axis) variables of an induction motor to the equivalent two-phase (dq-axis) variables can be performed by

\begin{equation}
\begin{bmatrix}
x_d \\
x_q
\end{bmatrix}
=
\frac{2}{3}
\begin{bmatrix}
\cos \theta & \cos(\theta - 2\pi/3) & \cos(\theta - 4\pi/3) \\
-\sin \theta & -\sin(\theta - 2\pi/3) & -\sin(\theta - 4\pi/3)
\end{bmatrix}
\begin{bmatrix}
x_a \\
x_b \\
x_c
\end{bmatrix} \tag{14.2-1}
\end{equation} 

where $x$ represents either current, voltage, or flux linkage, and $\theta$ is the angular displacement between the a-axis and d-axis of the three-phase and two-phase reference frames as shown in Fig. 14.2-1. The three-phase variables, $x_a, x_b$, and $x_c$, are in the \textit{stationary reference frame} which does not rotate in space whereas the two-phase variables, $x_d$ and $x_q$, are in the \textit{synchronous reference frame} whose direct (d) and quadrature (q) axes rotate in space at the synchronous speed $\omega_e$. Note that $\omega_e$ is the angular electrical (not mechanical) speed of the rotating magnetic field of the motor, given by

\begin{equation}
\omega_e = 2 \pi f_s \tag{14.2-2}
\end{equation} 

where $f_s$ is the frequency of the stator variables. The angle $\theta$ can be found from

\begin{equation}
\theta(t) = \int_{0}^{t} \omega_e(t) dt + \theta_0 \tag{14.2-3}
\end{equation} 

\begin{figure}[h]
\centering

\caption{Figure 14.2-1: Variables in three-phase (abc) stationary frame and two-phase (dq) synchronous frame.}
\end{figure}
\FloatBarrier

Note that the transformation equation of (14.2-1) is valid only for a three-phase balanced system, in which

\begin{equation}
x_a + x_b + x_c = 0 \tag{14.2-4}
\end{equation} 

Similarly, the two-phase variables in the synchronous frame can be transformed back to the three-phase stationary frame by

\begin{equation}
\begin{bmatrix}
x_a \\
x_b \\
x_c
\end{bmatrix}
=
\begin{bmatrix}
\cos \theta & -\sin \theta \\
\cos(\theta - 2\pi/3) & -\sin(\theta - 2\pi/3) \\
\cos(\theta - 4\pi/3) & -\sin(\theta - 4\pi/3)
\end{bmatrix}
\begin{bmatrix}
x_d \\
x_q
\end{bmatrix} \tag{14.2-5}
\end{equation} 

which is referred to as dq/abc transformation.

The relationship between a space vector and its phase variables is illustrated in Fig. 14.2-2a, where a current space vector $\vec{i}_s$ rotates at a certain speed $\omega$ in the stationary frame (refer to Chapter 6 for space vector definition). Its phase currents $i_{as}, i_{bs}$, and $i_{cs}$ can be obtained by decomposing $\vec{i}_s$ onto their corresponding abc-axes. Since the three axes are stationary in space, each of the phase currents varies one cycle over time when $\vec{i}_s$ rotates one revolution in space. If the length (magnitude) and the rotating speed of $\vec{i}_s$ are constant, the waveforms of the phase currents over time are sinusoidal with a phase displacement of $2\pi/3$ between each other.

\begin{figure}[h]
\centering

\caption{Figure 14.2-2: Decomposition of current vector $\vec{i}_s$.}
\end{figure}
\FloatBarrier

Figure 14.2-2b illustrates another case where the current vector $\vec{i}_s$ is in the dq-axis synchronous reference frame. Assuming that $\vec{i}_s$ rotates at the same speed as that of the dq-axis frame, the stator current angle $\phi$, which is the angle between $\vec{i}_s$ and the d-axis, is constant. The resultant dq-axis current components, $i_{ds}$ and $i_{qs}$, are of dc signals. As will be seen in the subsequent sections, this transformation can be utilized to simplify the simulation, design, and digital implementation of drive systems, where a three-phase ac signal can be effectively represented by a two-phase dc signal.

\subsection{3/2 Stationary Transformation}

With the rotating speed of the two-phase reference frame set at zero and its d-axis coincident with the a-axis of the three-phase frame ($\omega_e = 0$ and $\theta = 0$), both frames are stationary in space. The transformation of the three-phase variables to the two-phase variables can be obtained by setting $\theta$ in (14.2-1) to zero, from which

\begin{equation}
\begin{bmatrix}
x_d \\
x_q
\end{bmatrix}
=
\frac{2}{3}
\begin{bmatrix}
1 & -1/2 & -1/2 \\
0 & \sqrt{3}/2 & -\sqrt{3}/2
\end{bmatrix}
\begin{bmatrix}
x_a \\
x_b \\
x_c
\end{bmatrix} \tag{14.2-6}
\end{equation}

The above transformation is referred to as 3/2 transformation in this book. It is worth noting that the d-axis variable can be expressed as

\begin{equation}
x_d = \frac{2}{3} \left( x_a - \frac{1}{2}x_b - \frac{1}{2}x_c \right) = x_a \tag{14.2-7}
\end{equation}

which is equal to the a-axis variable $x_a$.

Similarly, the two-phase to three-phase stationary transformation, which is denoted 2/3 transformation, can be performed by

\begin{equation}
\begin{bmatrix}
x_a \\
x_b \\
x_c
\end{bmatrix}
=
\begin{bmatrix}
1 & 0 \\
-1/2 & \sqrt{3}/2 \\
-1/2 & -\sqrt{3}/2
\end{bmatrix}
\begin{bmatrix}
x_d \\
x_q
\end{bmatrix} \tag{14.2-8}
\end{equation}

\section{Induction Motor Dynamic Models}

There are two commonly used dynamic models for the induction motor. One is based on space vector theory and the other is derived from dq-axis theory. The space vector model features compact mathematical expressions and concise space vector diagram, whereas the dq-axis model does not need to use complex numbers or variables. Both models are equally valid for the analysis of transient and steady-state performance of the induction motor. In what follows, the two models are presented and their relationship is revealed.

\subsection{Space Vector Motor Model}

It is assumed in the following analysis that the induction motor is three-phase symmetrical and its magnetic core is linear with a negligible core loss. The space vector model for an induction motor is generally composed of three sets of equations [2]. The first set is the voltage equations, given by

\begin{equation}
\vec{v}_s = R_s \vec{i}_s + p \vec{\lambda}_s + j\omega \vec{\lambda}_s \tag{14.3-1}
\end{equation}

\begin{equation}
\vec{v}_r = R_r \vec{i}_r + p \vec{\lambda}_r + j(\omega - \omega_r)\vec{\lambda}_r \tag{14.3-1}
\end{equation}

where $\vec{v}_s$ and $\vec{v}_r$ are the stator and rotor voltage vectors, respectively; $\vec{i}_s$ and $\vec{i}_r$ are the stator and rotor current vectors, respectively; $\vec{\lambda}_s$ and $\vec{\lambda}_r$ are the stator and rotor flux-linkage vectors, respectively; $R_s$, $R_r$ are the stator and rotor winding resistance, respectively; $\omega$ is the rotating speed of an arbitrary reference frame; $\omega_r$ is the rotor angular speed (electrical); and $p$ is the derivative operator ($p = d/dt$).

The terms $j\omega \vec{\lambda}_s$ and $j(\omega - \omega_r)\vec{\lambda}_r$ on the right-hand side of (14.3-1) are referred to as speed voltages, which are induced by the rotation of the reference frame.

The second set is the flux-linkage equations

\begin{equation}
\vec{\lambda}_s = L_s \vec{i}_s + L_m \vec{i}_r \tag{14.3-2}
\end{equation}

\begin{equation}
\vec{\lambda}_r = L_r \vec{i}_r + L_m \vec{i}_s \tag{14.3-2}
\end{equation}

where $L_s = L_{ls} + L_m$ represents the stator self-inductance; $L_r = L_{lr} + L_m$ represents the rotor self-inductance; $L_{ls}$ and $L_{lr}$ are the stator and rotor leakage inductances, respectively; and $L_m$ is the magnetizing inductance. Note that all the rotor parameters and variables, such as $R_r$, $L_{lr}$, $\vec{i}_r$, and $\vec{\lambda}_r$, in the above equations are referred to the stator side.

The third set is the motion equation, given by

\begin{equation}
\frac{J}{P} p\omega_r = T_e - T_L \tag{14.3-3}
\end{equation}

\begin{equation}
T_e = \frac{3P}{2} \text{Re}(\vec{J} \vec{\lambda}_s \vec{i}_s^*) = -\frac{3P}{2} \text{Re}(\vec{J} \vec{\lambda}_r \vec{i}_r^*) \tag{14.3-3}
\end{equation}

where $J$ is the total moment of inertia of the rotor and load, $P$ is the number of pole pairs, $T_L$ is the load torque, and $T_e$ is the electromagnetic torque.

The above equations constitute the space vector model of the induction motor whose schematic representation is given in Fig. 14.3-1. The motor model is in the arbitrary reference frame that rotates in space at the arbitrary speed of $\omega$.

\begin{figure}[h]
\centering

\caption{Figure 14.3-1: Space vector model of an induction motor in the arbitrary reference frame.}
\end{figure}
\FloatBarrier

In the simulation and digital implementation of advanced control systems, the motor models in the synchronous and stationary reference frames are often employed. The synchronous-frame motor model can be easily obtained by setting the arbitrary speed $\omega$ in (14.3-1) to the synchronous speed $\omega_e$. Figure 14.3-2a shows the equivalent circuit of a squirrel cage motor in the synchronous frame, where the rotor winding is shorted ($\vec{v}_r = 0$) and $\omega_{sl}$ is the angular slip frequency, given by

\begin{equation}
\omega_{sl} = \omega_e - \omega_r \tag{14.3-4}
\end{equation}

To obtain the model in the stationary (stator) frame, we can set the arbitrary speed $\omega$ of the rotating reference frame to zero. The resultant equivalent circuit is shown in Fig. 14.3-2b.

\begin{figure}[h]
\centering

\caption{Figure 14.3-2: Space vector models for a squirrel cage induction motor.}
\end{figure}
\FloatBarrier

\subsection{dq-Axis Motor Model}

The induction motor dq-axis model can be derived using three-phase circuit theory and then transformed into the two-phase (dq-axis) frame [1]. Alternatively, it can

also be obtained by decomposing the space vectors in the space vector motor model into the d- and q-axis components [2], that is,

\begin{equation}
\vec{v}_s = v_{ds} + jv_{qs}, \quad \vec{i}_s = i_{ds} + ji_{qs}, \quad \vec{\lambda}_s = \lambda_{ds} + j\lambda_{qs} \tag{14.3-5}
\end{equation}

\begin{equation}
\vec{v}_r = v_{dr} + jv_{qr}, \quad \vec{i}_r = i_{dr} + ji_{qr}, \quad \vec{\lambda}_r = \lambda_{dr} + j\lambda_{qr} \tag{14.3-5}
\end{equation}

Substituting (14.3-5) to (14.3-1), the dq-axis voltage equations for the induction motor can be obtained:

\begin{equation}
v_{ds} = R_s i_{ds} + p\lambda_{ds} - \omega \lambda_{qs} \tag{14.3-6}
\end{equation}
\begin{equation}
v_{qs} = R_s i_{qs} + p\lambda_{qs} + \omega \lambda_{ds} \tag{14.3-6}
\end{equation}
\begin{equation}
v_{dr} = R_r i_{dr} + p\lambda_{dr} - (\omega - \omega_r)\lambda_{dr} \tag{14.3-6}
\end{equation}
\begin{equation}
v_{qr} = R_r i_{qr} + p\lambda_{qr} + (\omega - \omega_r)\lambda_{dr} \tag{14.3-6}
\end{equation}

where the stator and rotor flux-linkages can be calculated by

\begin{equation}
\lambda_{ds} = L_s i_{ds} + L_m (i_{ds} + i_{dr}) \tag{14.3-7}
\end{equation}
\begin{equation}
\lambda_{qs} = L_s i_{qs} + L_m (i_{qs} + i_{qr}) \tag{14.3-7}
\end{equation}
\begin{equation}
\lambda_{dr} = L_r i_{dr} + L_m (i_{ds} + i_{dr}) \tag{14.3-7}
\end{equation}
\begin{equation}
\lambda_{qr} = L_r i_{qr} + L_m (i_{qs} + i_{qr}) \tag{14.3-7}
\end{equation}

The electromagnetic torque can be expressed in a number of ways. Some of the commonly used expressions are

\begin{equation}
T_e = \left\{
\begin{array}{l}
\frac{3P}{2}(i_{qs}\lambda_{ds} - i_{ds}\lambda_{qs}) \\
\frac{3PL_m}{2}(i_{qs}i_{dr} - i_{ds}i_{qr}) \\
\frac{3PL_m}{2L_r}(i_{qs}\lambda_{dr} - i_{ds}\lambda_{qr})
\end{array} \tag{14.3-8}
\right.
\end{equation}

Equations (14.3-6) to (14.3-8) together with the motion equation of (14.3-3) represent the dq-axis model of the induction motor, whose equivalent circuit is shown in Fig. 14.3-3.

\begin{figure}[h]
\centering

\caption{Figure 14.3-3: Induction motor dq-axis model in the arbitrary reference frame.}
\end{figure}
\FloatBarrier

\subsection{Induction Motor Transient Characteristics}

It is instructive to study transient characteristics of the induction motor during free acceleration using the dynamic motor models. The motor under investigation is a low-power squirrel cage motor with the following parameters: $V_{LL} = 208 \, V$, 60Hz, $Z_{base} = 15.4 \, \Omega$, $R_s = 0.068 \, pu$, $R_r = 0.045 \, pu$, $L_{ls} = L_{lr} = 0.058 \, pu$, $L_m = 1.95 \, pu$, $P = 1$, and $J = 0.02 \, kg\cdot m^2$. Figure 14.3-4 shows the block diagram for computer simulation with the motor model in the stationary frame ($\omega = 0$). The three-phase supply voltages $v_{as}$, $v_{bs}$, and $v_{cs}$ are transformed to the dq-axis stator voltages $v_{ds}$ and $v_{qs}$ by the 3/2 transformation. The simulated dq-axis stator currents $i_{ds}$ and $i_{qs}$ are then converted to the three-phase currents $i_{as}$, $i_{bs}$, and $i_{cs}$ by the 2/3 transformation.

\begin{figure}[h]
\centering

\caption{Figure 14.3-4: Block diagram for simulation of motor free acceleration using the stationary-frame motor model.}
\end{figure}
\FloatBarrier

\begin{figure}[h]
\centering

\caption{Figure 14.3-5: Waveforms of an induction motor during free acceleration.}
\end{figure}
\FloatBarrier

Figure 14.3-5a shows simulated transient waveforms of the stator current $i_{as}$ and rotor speed $n_r$ during motor free acceleration (the motor starts under the rated voltage and frequency without mechanical load). The rotor speed $n_r$, in rpm relates to the angular electrical rotor speed $\omega_r$ by

\begin{equation}
n_r = \frac{30}{\pi P} \omega_r \tag{14.3-9}
\end{equation}

The peak starting current is approximately 8.4 pu, which represents the rms starting current of 5.9 pu. The starting time is around 0.5 s due to the low moment of inertia and high starting current. The measured waveforms during the free acceleration are given in Fig. 14.3-5b, which match with the simulated results very well.

\begin{figure}[h]
\centering

\caption{Figure 14.3-6: Stator current waveforms of an induction motor during a three-phase fault.}
\end{figure}
\FloatBarrier

Figure 14.3-6 shows simulated and measured transient waveforms of the motor during a three-phase fault. The motor operates near its synchronous speed when its three-phase terminals are shorted. The maximum peak stator current is close to that during the free acceleration. The measured waveforms correlate closely with the simulated ones.

\begin{figure}[h]
\centering

\caption{Figure 14.3-7: Block diagram for simulation of motor free acceleration using the synchronous-frame motor model.}
\end{figure}
\FloatBarrier

Figure 14.3-7 illustrates the simulation block diagram with the motor model in the synchronous frame. Using the abc/dq and dq/abc transformation blocks, the three-phase supply voltages $v_{as}$, $v_{bs}$, and $v_{cs}$ in the stationary frame can be transformed to the dq-axis voltages $v_{ds}$ and $v_{qs}$ in the synchronous frame while the simulated dq-axis currents $i_{ds}$ and $i_{qs}$ in the synchronous frame can be converted to three-phase currents $i_{as}$, $i_{bs}$, and $i_{cs}$ in the stationary frame. The angle $\theta$ in the transformation blocks can be obtained by the 3/2 transformation and tan$^{-1}$ blocks shown in the figure or using Eq. (14.2-3) directly.

\begin{figure}[h]
\centering

\caption{Figure 14.3-8: Simulated waveforms for motor free acceleration using the synchronous-frame motor model.}
\end{figure}
\FloatBarrier

Figure 14.3-8a shows the simulated current waveforms for $i_{as}$, $i_{ds}$, and $i_{qs}$ during motor free acceleration. The waveform for $i_{as}$ in the stationary frame is exactly the same as that in Fig. 14.3-5. The dq-axis currents $i_{ds}$ and $i_{qs}$ are in the synchronous frame, and therefore they are dc signals in steady state. The amplitude of the stator current $\vec{i}_s$ can be obtained by $\vec{i}_s = \sqrt{i_{ds}^2 + i_{qs}^2}$. The dq-axis voltages $v_{ds}$ and $v_{qs}$ in the synchronous frame are of a constant dc, and therefore they are not shown in the figure.

The stator current angle $\phi$, which is the angle between $\vec{i}_s$ and the d-axis as shown in Fig. 14.2-2b, will affect waveforms for $i_{ds}$ and $i_{qs}$. The waveforms in Fig. 14.3-8a are obtained with $\phi = 0$ by adjusting the initial angle $\theta_0$ such that the d-axis of the synchronous frame is aligned with $\vec{i}_s$. This leads to $i_{qs} = 0$ and $i_{ds} = i_s$ when the motor is in steady-state operation. If the q-axis of the synchronous frame is aligned with $\vec{i}_s$ ($\phi = 90^\circ$), the steady-state dq-axis currents are $i_{qs} = i_s$ and $i_{ds} = 0$. However, the waveform for $i_s$ is not affected by $\phi$.

The torque response during the motor free acceleration is shown in Fig. 14.3-8b. Although it is obtained with the motor model in the synchronous frame, the response remains the same for the motor model in any other reference frames.

\clearpage
\section{Principle of Field-Oriented Control (FOC)}

\subsection{Field Orientation}

It is well known that the dc motor drive has an excellent dynamic performance. This is mainly due to the decoupled (separate) control of stator magnetic field and electromagnetic torque of the motor. The torque is developed by the interaction of two perpendicular magnetic fields. One field is generated by the field current $i_f$ in the stator winding, and the other is produced by the armature (rotor) current $i_a$. The developed torque can be expressed as

\begin{equation}
T_e = K_a \lambda_f i_a \tag{14.4-1}
\end{equation}

where $K_a$ is an armature constant and $\lambda_f$ is the flux produced by $i_f$. In high-performance dc drives, $\lambda_f$ is normally kept constant by keeping $i_f$ constant, and thus the torque $T_e$ is proportional to and can be directly controlled by $i_a$.

The field-oriented control, also known as vector control, for induction motor emulates the dc motor control. Using a proper field orientation, the stator current can be decomposed into a flux-producing component and a torque-producing component. These two components are then controlled separately.

The field orientation can be generally classified into stator flux, air-gap flux, and rotor flux orientations [3, 4]. Since the rotor flux orientation is extensively used in ac drives, this scheme is to be analyzed in detail. Its operating principle can be easily applied to the other two field orientation schemes.

\begin{figure}[h]
\centering

\caption{Figure 14.4-1: Rotor flux field orientation (the d-axis is aligned with $\vec{\lambda}_r$).}
\end{figure}
\FloatBarrier

The rotor flux orientation is achieved by aligning the d-axis of the synchronous reference frame with the rotor flux vector $\vec{\lambda}_r$ as shown in Fig. 14.4-1. The resultant d- and q-axis rotor flux components are

\begin{equation}
\lambda_{qr} = 0 \quad \text{and} \quad \lambda_{dr} = \lambda_r \tag{14.4-2}
\end{equation}

where $\lambda_r$ is the magnitude of $\vec{\lambda}_r$. Substituting (14.4-2) into the last equation of (14.3-8) yields

\begin{equation}
T_e = K_r \lambda_r i_{qs} = K_r \lambda_r i_{qs} \tag{14.4-3}
\end{equation}

where $K_r = 3PL_m/2L_r$. Equation (14.4-3) indicates that with the rotor field orientation the torque expression for the induction motor is similar to that of a dc motor. If $\lambda_r$ can be kept constant during the motor operation, the developed torque can be directly controlled by the q-axis stator current $i_{qs}$.

The stator current vector $\vec{i}_s$ in Fig. 14.4-1 can be resolved into two components along the dq-axes. The d-axis current $i_{ds}$ is referred to as flux-producing current while the q-axis current $i_{qs}$, which is perpendicular to $i_{ds}$, is the torque-producing current. In the field-oriented control, $i_{ds}$ is normally kept at its rated value while $i_{qs}$ is controlled independently. With the decoupled control for $i_{ds}$ and $i_{qs}$, a high-performance drive can be realized.

One of the key issues associated with the rotor flux-oriented control is to accurately determine the rotor flux angle $\theta_f$ for field orientation. Various schemes can be used to find $\theta_f$. For instance, it can be calculated from measured stator voltages and currents, or it can be found from

\begin{equation}
\theta_f = \theta_r + \theta_{sl} \tag{14.4-4}
\end{equation}

where $\theta_r$ and $\theta_{sl}$ are the measured rotor position angle and calculated slip angle, respectively.

\subsection{General Block Diagram of FOC}

Depending on how the rotor flux angle $\theta_f$ is obtained, the control schemes can be classified into direct and indirect field-oriented controls. If $\theta_f$ is obtained by using flux-sensing devices embedded inside the motor or using measured motor terminal voltages and currents, the method is referred to as direct field-oriented control. If the rotor flux angle $\theta_f$ is obtained from detected rotor position angle $\theta_r$ and calculated slip angle $\theta_{sl}$ as shown in (14.4-4), this scheme is known as \textit{indirect field-oriented control} [3, 4].

\begin{figure}[h]
\centering

\caption{Figure 14.4-2: General block diagram of rotor flux FOC.}
\end{figure}
\FloatBarrier

A general block diagram of an induction motor drive with rotor flux-oriented control is shown in Fig. 14.4-2. Since the essence of the FOC is the decoupled control of the rotor flux $\lambda_r$ and electromagnetic torque $T_e$, these two variables are controlled separately. The torque reference $T_e^*$ is generated by \textit{Speed Controller} based on the reference speed $\omega_r^*$ and the detected or estimated rotor speed $\omega_r$. The rotor flux reference $\lambda_r^*$ is a function of $\omega_r^*$. When the motor operates at or below its rated speed, $\lambda_r^*$ is normally kept at its rated value. With the rated speed exceeded, $\lambda_r^*$ should be weakened accordingly such that the stator voltage and the output power of the motor would not exceed their ratings.

The two references $\lambda_r^*$ and $T_e^*$ are then sent to \textit{Flux/Torque Controller}, where they are compared with calculated rotor flux $\lambda_r$ and torque $T_e$ for a closed-loop control. The \textit{Flux/Torque Controller} generates reference signals for the PWM block, which produces gate signals for the inverter to adjust its output voltage and frequency.

Based on the measured stator voltage and current variables and the motor model, the \textit{Flux/Torque Calculator} calculates (1) the rotor flux angle $\theta_f$ for field orientation, (2) the rotor flux magnitude $\lambda_r$, or the flux-producing current $i_{ds}$, (3) the electromagnetic torque $T_e$ or the torque-producing current $i_{qs}$, and (4) the rotor speed $\omega_r$. Depending on drive system requirements and the type of the FOC scheme employed, the rotor speed $\omega_r$ may also be directly detected by a digital speed sensor. It is worth noting that the \textit{Flux/Torque Calculator}, also known as \textit{Flux/Torque Observer} or \textit{Estimator} in the literature, is the most important functional block in the FOC scheme.

\clearpage
\section{Direct Field-Oriented Control}

\subsection{System Block Diagram}

\begin{figure}[h]
\centering

\caption{Figure 14.5-1: Direct field-oriented control with rotor flux orientation.}
\end{figure}
\FloatBarrier

Figure 14.5-1 shows a typical block diagram of direct field-oriented control for induction motor, where the rotor speed control is not shown for simplicity. There are three feedback control loops, one for the rotor flux linkage $\lambda_r$, one for the d-axis (flux-producing) stator current $i_{ds}$, and another for the q-axis (torque-producing) stator current $i_{qs}$.

For the rotor flux control, the calculated $\lambda_r$ is compared with its reference $\lambda_r^*$ to generate the d-axis stator current reference $i_{ds}^*$ through flux controller (FC). The q-axis stator current reference $i_{qs}^*$ is generated according to the torque reference $T_e^*$. The feedback dq-axis stator currents $i_{ds}$ and $i_{qs}$ are compared with their references, and the errors are sent to current controllers to generate stator voltage references $v_{ds}^*$ and $v_{qs}^*$. The dq-axis voltages in the synchronous frame are then transformed to the three-phase stator voltages $v_{as}^*$, $v_{bs}^*$, and $v_{cs}^*$ in the stationary frame for the PWM block. Various PWM schemes can be used. If a carrier-based modulation scheme is employed, $v_{as}^*$, $v_{bs}^*$, and $v_{cs}^*$ are the modulating signals that are compared with a triangular carrier wave to generate PWM gating for the switching devices in the inverter.

As shown in Fig. 14.5-1, the rotor flux angle $\theta_f$ is used in the abc/dq and dq/abc transformation blocks for field orientation. The variables to the left of the transformation blocks are all dc signals in the synchronous frame, while those on the right side of the transformation blocks are all ac variables in the stationary frame.

\subsection{Rotor Flux Calculator}

Based on the stationary-frame motor model in Fig. 14.3-2b, the stator flux vector can be expressed as

\begin{equation}
\vec{\lambda}_s = \int (\vec{v}_s - R_s \vec{i}_s) \, dt \tag{14.5-1}
\end{equation}

The rotor flux vector can be found from the flux-linkage equations (14.3-2):

\begin{equation}
\vec{\lambda}_r = L_r \frac{\vec{\lambda}_s - L_s \vec{i}_s}{L_m} + L_m \vec{i}_s = \frac{L_r}{L_m} (\vec{\lambda}_s - \sigma L_s \vec{i}_s) \tag{14.5-2}
\end{equation}

where $\sigma$ is the total leakage factor, defined by

\begin{equation}
\sigma = 1 - \frac{L_m^2}{L_s L_r} \tag{14.5-3}
\end{equation}

Decomposing the rotor flux $\vec{\lambda}_r$ into the d- and q-axis components, we have

\begin{equation}
\lambda_{dr} = \frac{L_r}{L_m} (\lambda_{ds} - \sigma L_s i_{ds}) \tag{14.5-4}
\end{equation}
\begin{equation}
\lambda_{qr} = \frac{L_r}{L_m} (\lambda_{qs} - \sigma L_s i_{qs}) \tag{14.5-4}
\end{equation}

from which the magnitude and angle of the rotor flux are

\begin{equation}
\lambda_r = \sqrt{\lambda_{dr}^2 + \lambda_{qr}^2} \tag{14.5-5}
\end{equation}
\begin{equation}
\theta_r = \tan^{-1} \frac{\lambda_{qr}}{\lambda_{dr}} \tag{14.5-5}
\end{equation}

The following can be noted from (14.5-1) to (14.5-5):
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

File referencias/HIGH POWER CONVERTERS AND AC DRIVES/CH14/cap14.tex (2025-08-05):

\documentclass[letterpaper,12pt]{article} % Tamaño carta y fuente de 12 puntos
\usepackage[utf8]{inputenc} % Codificación de caracteres
\usepackage[spanish]{babel} % Idioma del documento
\usepackage{graphicx} % Paquete para incluir imágenes
\usepackage{amsmath} % Paquete para matemáticas avanzadas
\usepackage{amssymb} % Paquete para símbolos matemáticos adicionales
\usepackage[margin=1in]{geometry} % Ajuste de márgenes
\usepackage{chngcntr} % Paquete para cambiar el contador
\usepackage{caption} % Paquete para personalizar leyendas
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

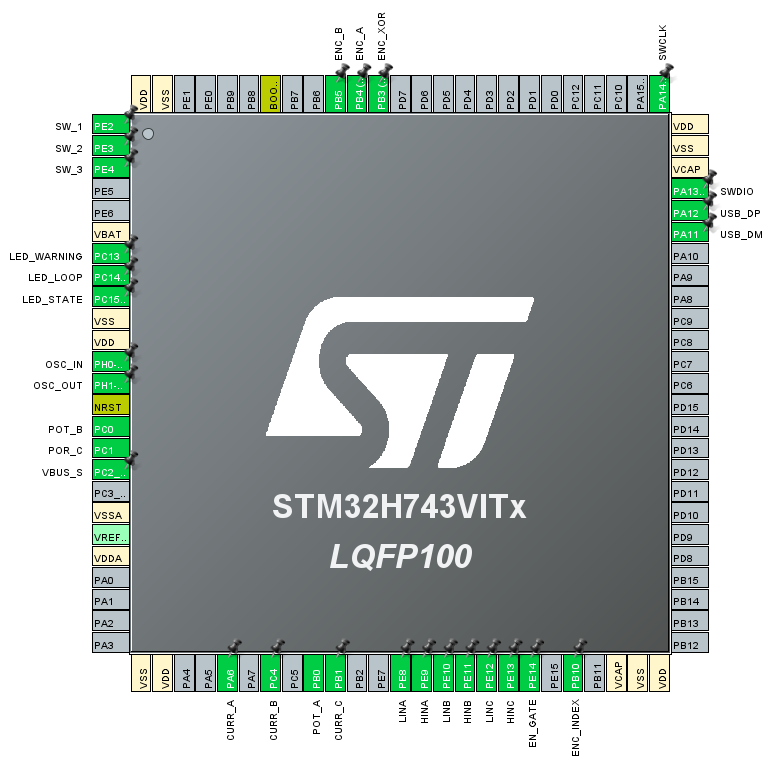
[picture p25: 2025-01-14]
manuscrito/anexos/pinout.png

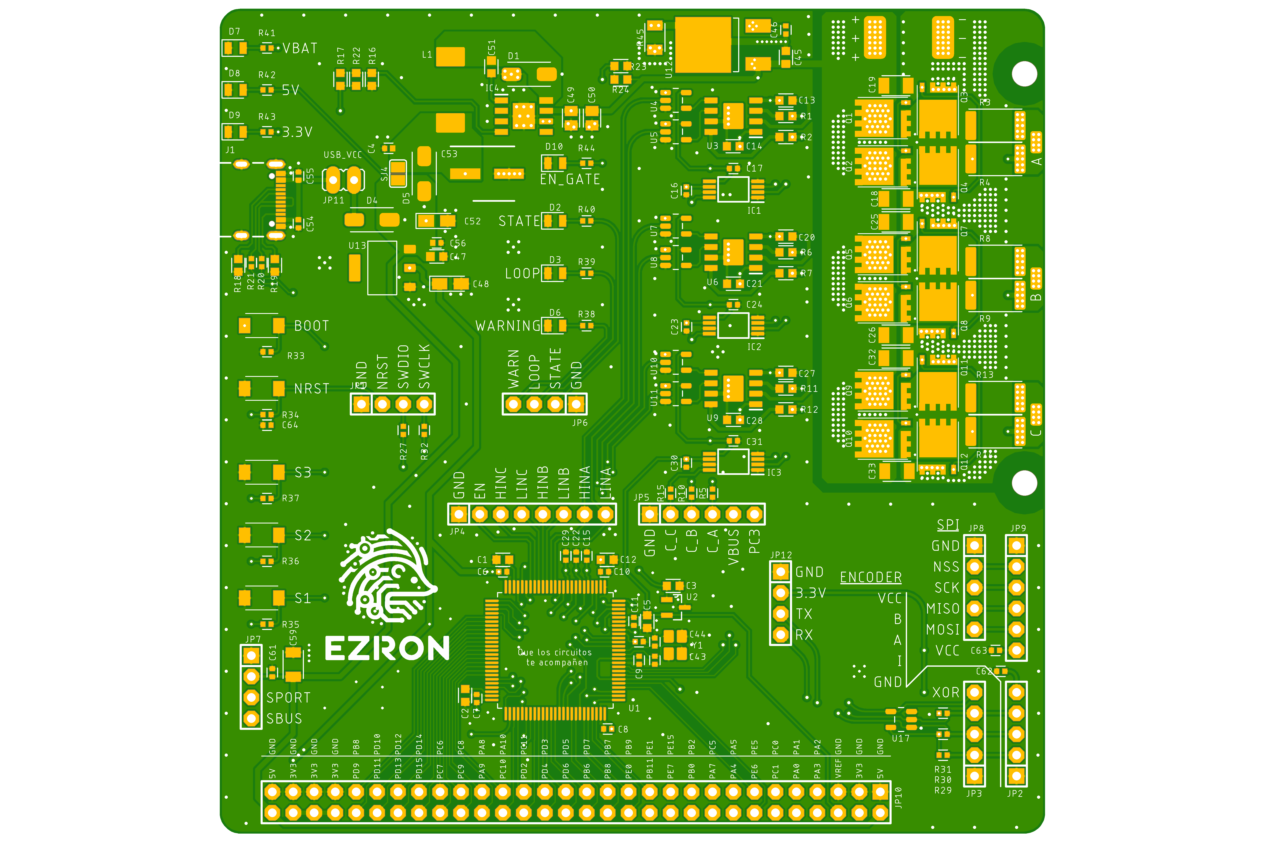
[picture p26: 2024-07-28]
Hardware/EZFOC_V1_TOP.png

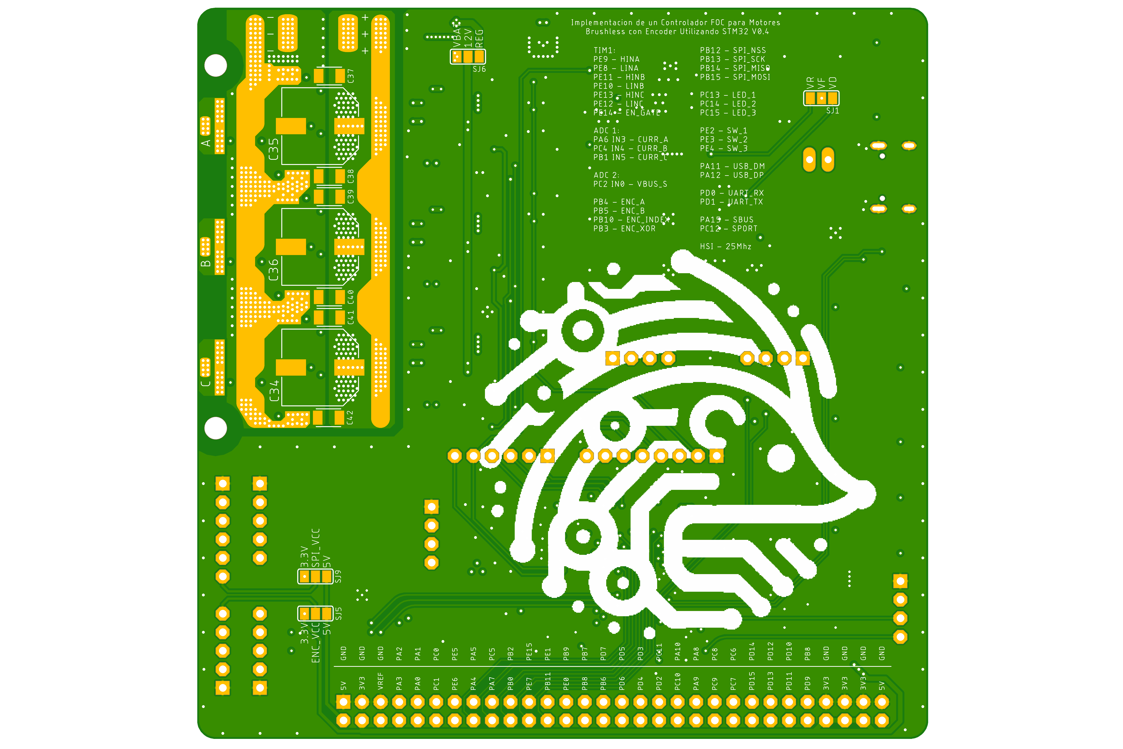
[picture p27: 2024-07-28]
Hardware/EZFOC_V1_BUTTON.png

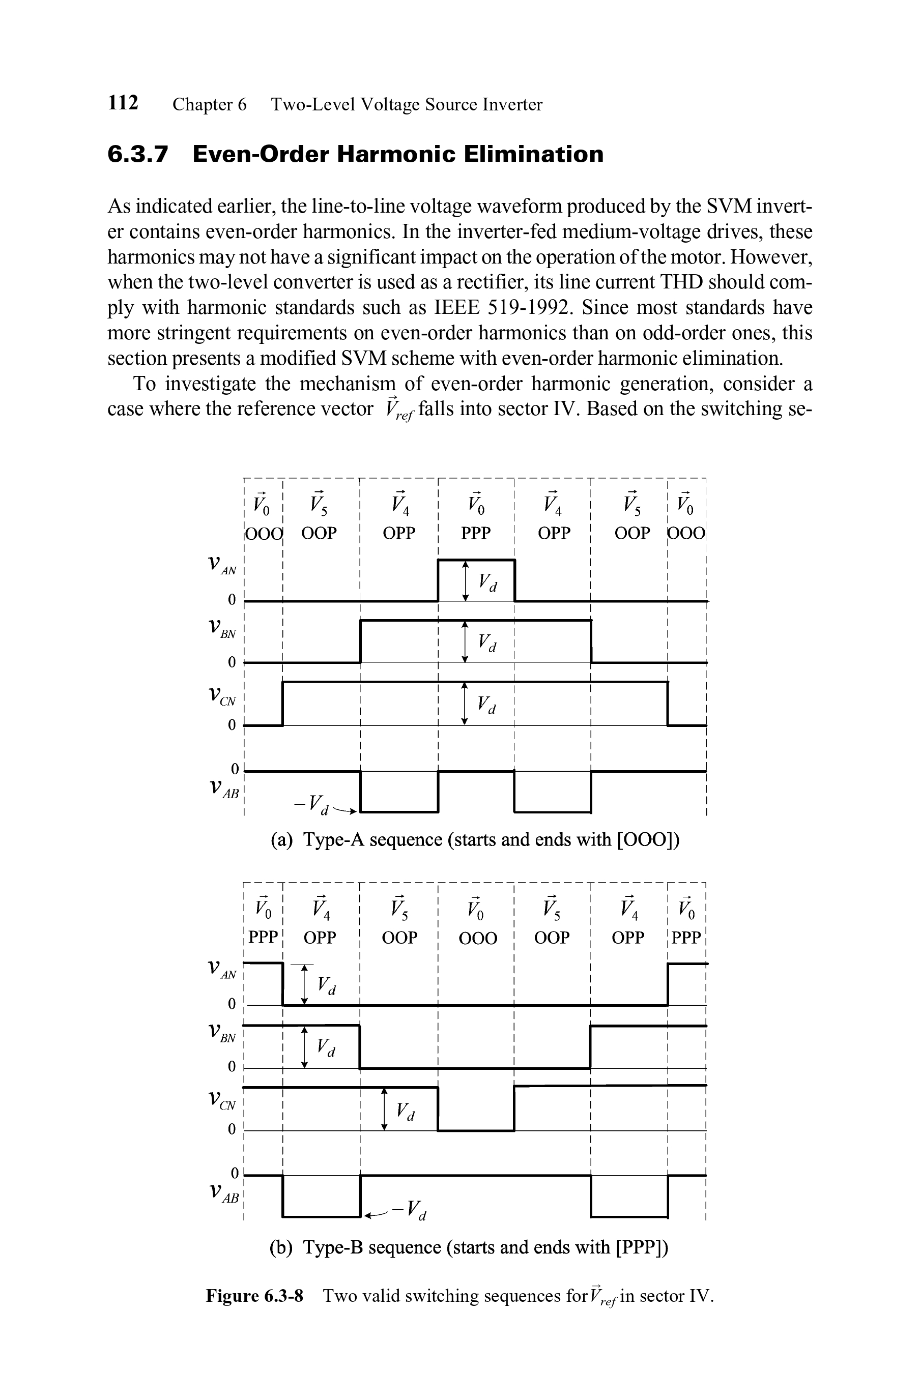
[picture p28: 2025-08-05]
referencias/HIGH POWER CONVERTERS AND AC DRIVES/CH6/paginas/HIGH POWER CONVERTERS AND AC DRIVES-CH6_page-0018.jpg

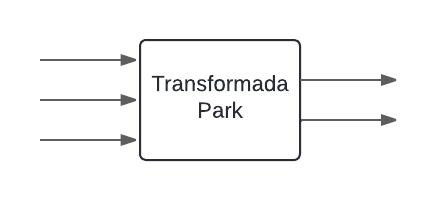
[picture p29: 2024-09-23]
manuscrito/imagenes/extras/Transformada de park.png

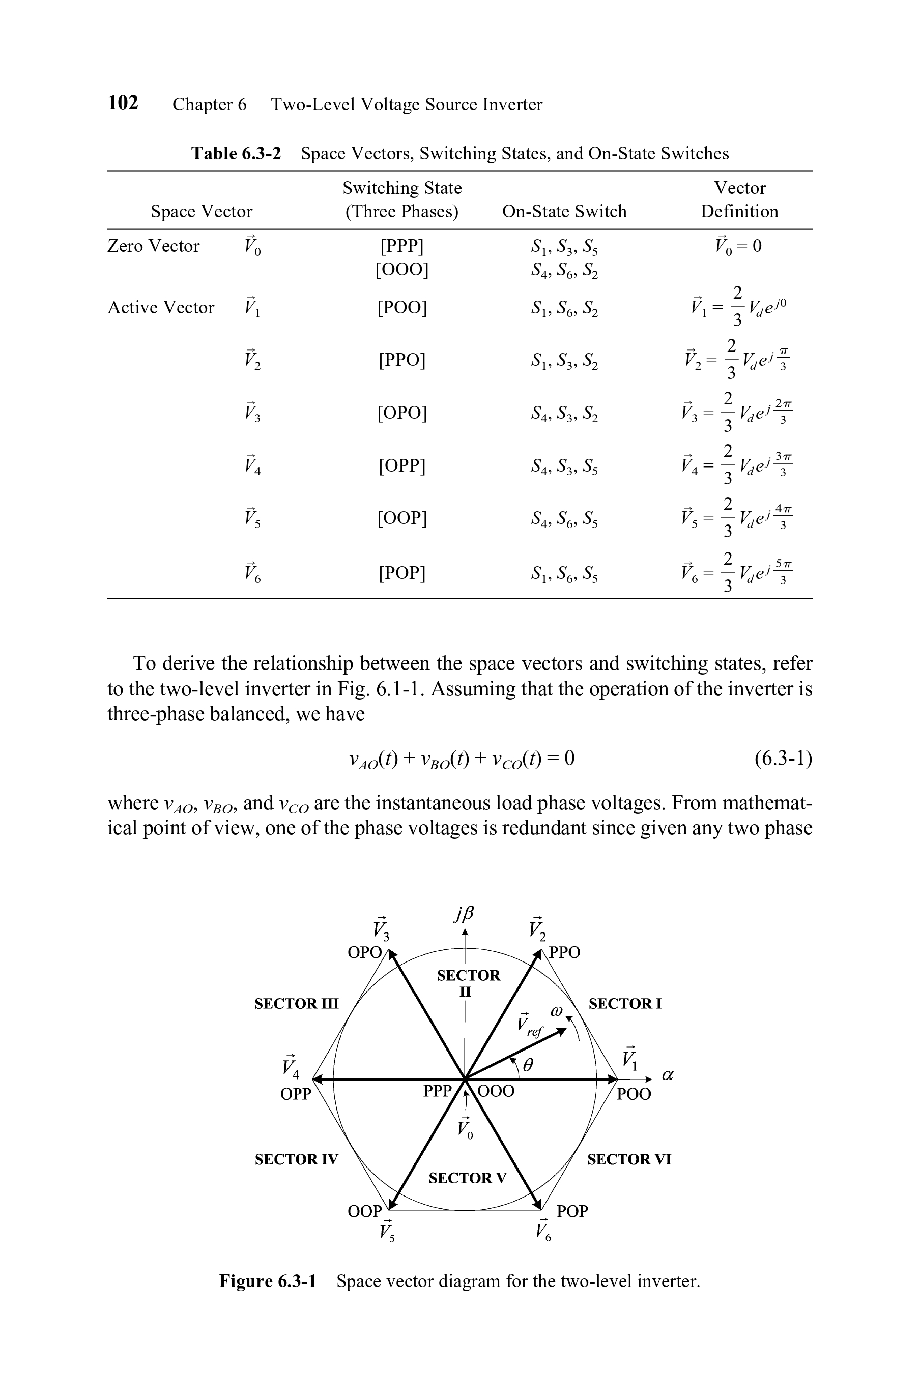
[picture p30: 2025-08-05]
referencias/HIGH POWER CONVERTERS AND AC DRIVES/CH6/paginas/HIGH POWER CONVERTERS AND AC DRIVES-CH6_page-0008.jpg

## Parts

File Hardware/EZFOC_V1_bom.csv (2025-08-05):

Comment | Designator | Footprint | LCSC Part #
 | JP1 | 1X04
 | JP6 | 1X04
 | JP7 | 1X04
 | JP12 | 1X04
 | JP2 | 1X05
 | JP3 | 1X05
 | JP8 | 1X05
 | JP5 | 1X06
 | JP9 | 1X06
 | JP4 | 1X08
 | JP10 | 2X30
 | JP11 | JP1
 | SJ4 | SJ
 | SJ1 | SJ_2
 | SJ5 | SJ_2
 | SJ6 | SJ_2
 | SJ9 | SJ_2
0 | R45 | 1206 | C17888
0.1uF | C4 C6 C7 C8 C9 C10 C11 C15 C16 C17 C22 C23 C24 C29 C30 C31 C46 C54 C55 C56 C61 C62 C63 C64 | 0402
0.1uF 35V | C13 C20 C27 | 0603
0.01uF | C51 | 0603
1 | R1 R2 R6 R7 R11 R12 | 0603
1.6k | R16 | 0603
1k | R38 R39 R40 R42 R43 R44 | 0402
1m | R3 R4 R8 R9 R13 R14 | 2512 | C7370895
1nF | C57 | 0402
1uF 35V | C3 C5 C45 C47 | 0603
2.2uF | C1 C2 | 0603
2.2uF 16V | C14 C21 C28 | 0603
2.4M | R22 | 0603
3.3k | R29 R30 R31 | 0402
4.7uF | C12 | 0603
5.1k | R17 R18 R19 | 0603
8.2k | R23 | 0603
10 | R5 R10 R15 | 0402
10k | R33 R35 R36 R37 | 0402
10uF 35V | C49 C50 | 0805
10uF | C48 C52 | CAPMP3216X180N | C7171 ASYI
12k | R41 | 0402
12pF | C43 C44 | 0402
15uH | L1 | SMD6.6X7.3MM | C2847544
22 | R20 R21 R27 R32 | 0402
22uF 35V | C18 C19 C25 C26 C32 C33 C37 C38 C39 C40 C41 C42 C59 | 1206
75k | R24 | 0603
220uF | C53 | CAPAE660X800N | C72494
470uF 35V | C34 C35 C36 | CAPAE1030X1050N | C2980172
AMS1117-3.3 | U13 | SOT229P700X180-4N | C6186
B340A | D1 D4 D5 | DIOM5226X240N | C8678
BSC011N03LSI_FL | Q1 Q2 Q3 Q4 Q5 Q6 Q7 Q8 Q9 Q10 Q11 Q12 | TDSON-8FL | C534283
CRISTAL_25MHZ_3225 | Y1 | SMD3225-4P | C9006
INA240A1PW | IC1 IC2 IC3 | SOP65P640X120-8N | C93965
L78M12CDT-TR | U12 | VREG_L78M12CDT-TR | C16424
LED_BLUE | D2 D3 D6 D7 D8 D9 D10 | LEDC2012X110N_FLAT-B | C2297
NC | R34 | 0402
PAD1.27X2.54 | A A1 B B1 C C65 | SMD1 27-2 54
PAD2.54X5.08 | PAD1 PAD2 PAD3 PAD4 | SMD2 54-5 08
REF3033AIDBZR | U2 | SOT95P237X112-3N | C36658
SN74LVC1G08DBVR | U4 U5 U7 U8 U10 U11 | SOT95P280X145-5N | C7666
SN74LVC1G86DBVR | U17 | SOT95P280X145-5N | C402161
STM32H743VIT6 | U1 | LQFP100 | C114409
TPS5430DDAR | IC4 | SOIC127P600X170-9N | C9864
TS-1088 | BOOT NRST S1 S2 S3 | SKRKAEE020 | C720477
TYPE-C_16PIN_2MD__073_C | J1 | GCT_USB4105-GF-A
UCC27211AQDDARQ1 | U3 U6 U9 | SOIC127P600X170-9N | C485921

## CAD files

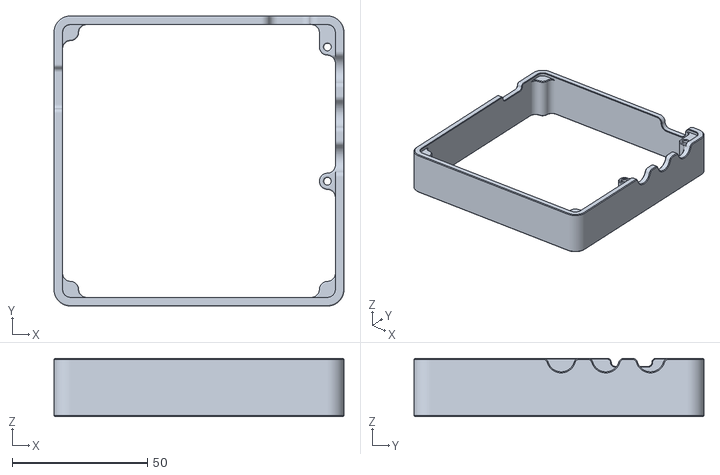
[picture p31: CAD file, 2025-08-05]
Hardware/3D/Base_PCB inclinada.stl
107.2 x 107.2 x 21.6

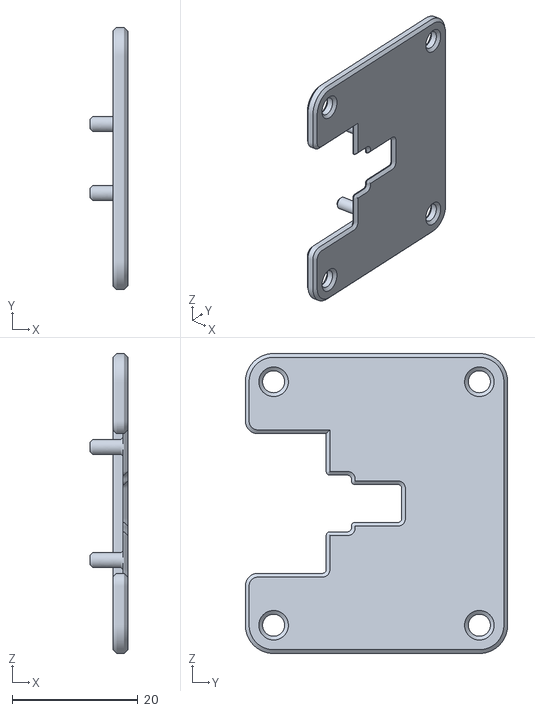
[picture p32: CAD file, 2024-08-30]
Hardware/3D/base_motor_encoder_AS5047_3.stl
6.00 x 41.7 x 47.7

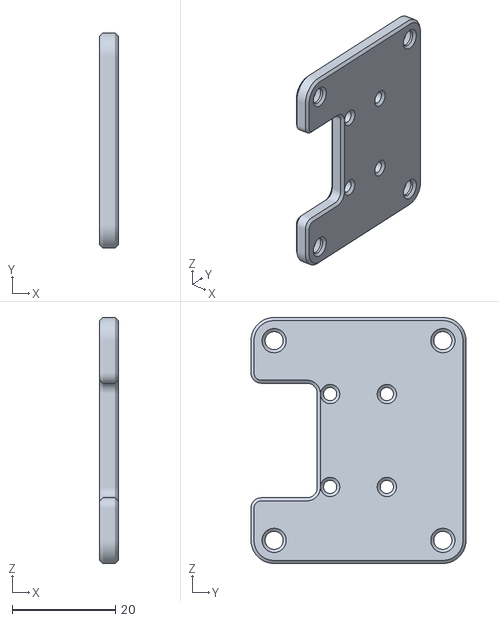
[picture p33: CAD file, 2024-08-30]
Hardware/3D/base_motor_tapa_AS5047_4.stl
3.60 x 41.7 x 47.7

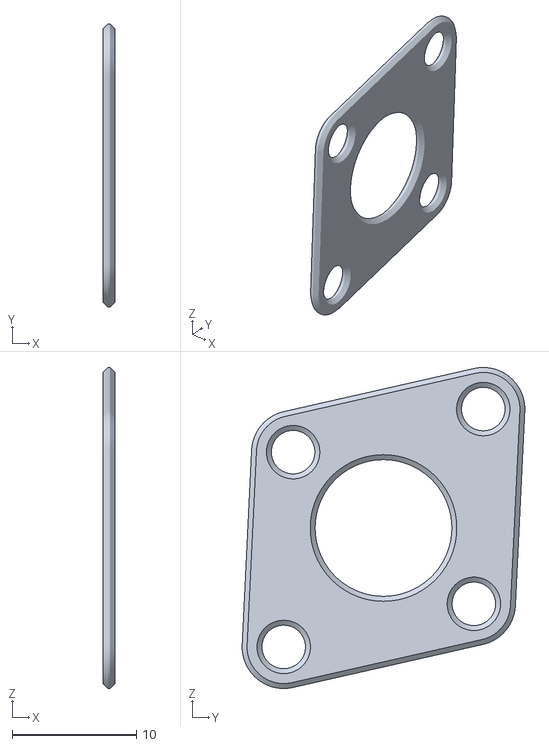
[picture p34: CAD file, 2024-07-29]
Hardware/3D/base_motor_separador_2.stl
1.00 x 22.8 x 25.8

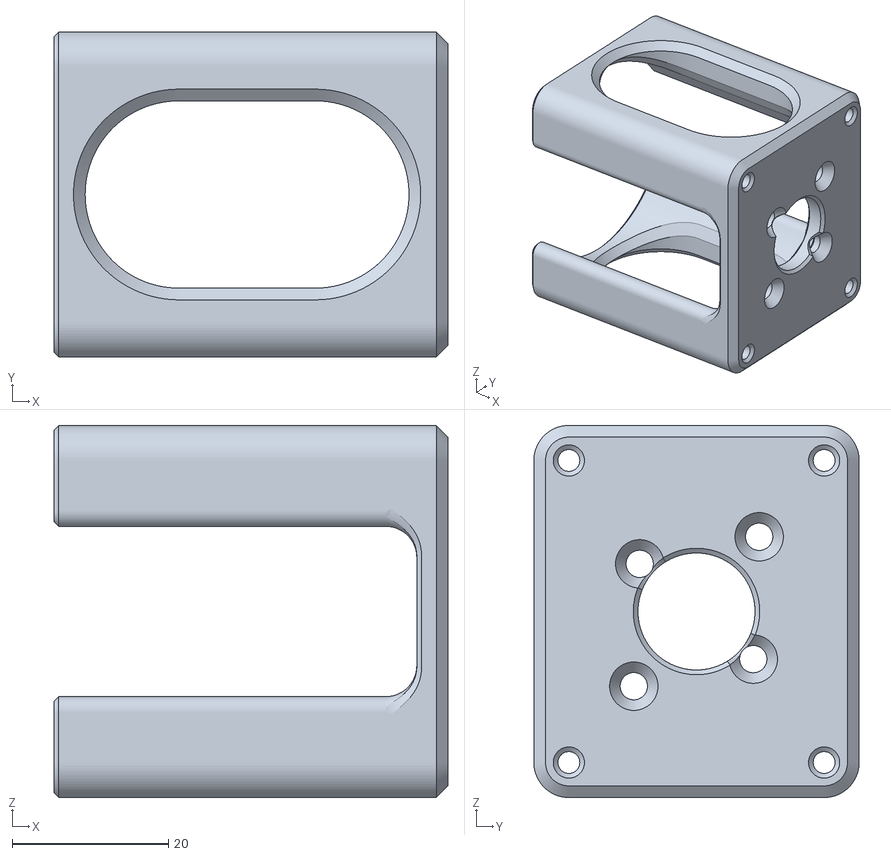
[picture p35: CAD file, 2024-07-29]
Hardware/3D/base_motor_cuerpo_1.stl
50.5 x 41.7 x 47.7

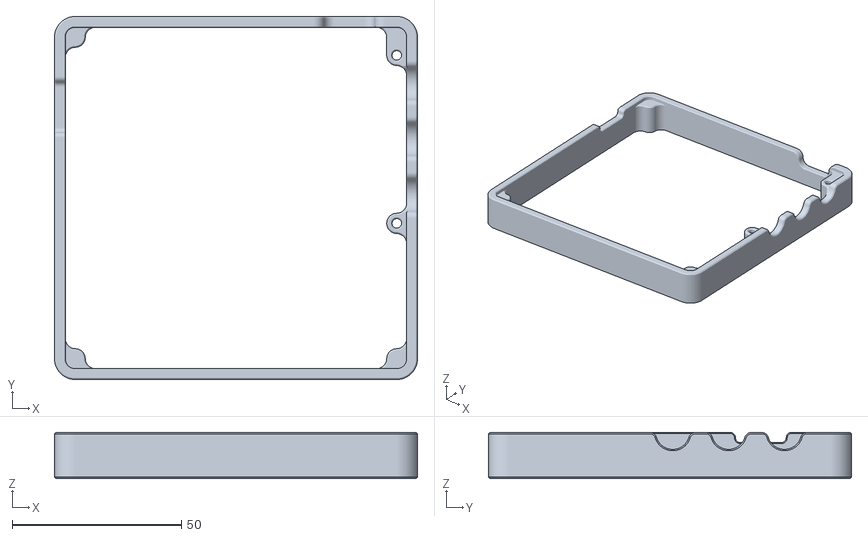
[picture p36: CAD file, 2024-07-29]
Hardware/3D/Base_PCB.stl
107.2 x 107.2 x 13.6

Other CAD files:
Hardware/3D/Base_PCB.ipt
Hardware/3D/Pieza2.ipt
Hardware/3D/base_motor.iam
Hardware/3D/base_motor.ipt
Hardware/3D/cuerpo.ipt
Hardware/3D/encoder_AS5047.ipt
Hardware/3D/separador.ipt
Hardware/3D/tapa_AS5047.ipt

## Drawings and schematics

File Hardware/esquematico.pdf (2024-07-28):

ABCDE | 1 | 2 | 3 | 4 | 5 | 6 | 7 | 8 | ABCDE 1 | 2 | 3 | 4 | 5 | 6 | 7 | 8

# PA10 PA9 PA8 PA7 PA5 PA4 PA3 PA2 PA1 PA0 PB0 PB2 PB6 PB7 PB8 PB9 PB11 SPI_NSS

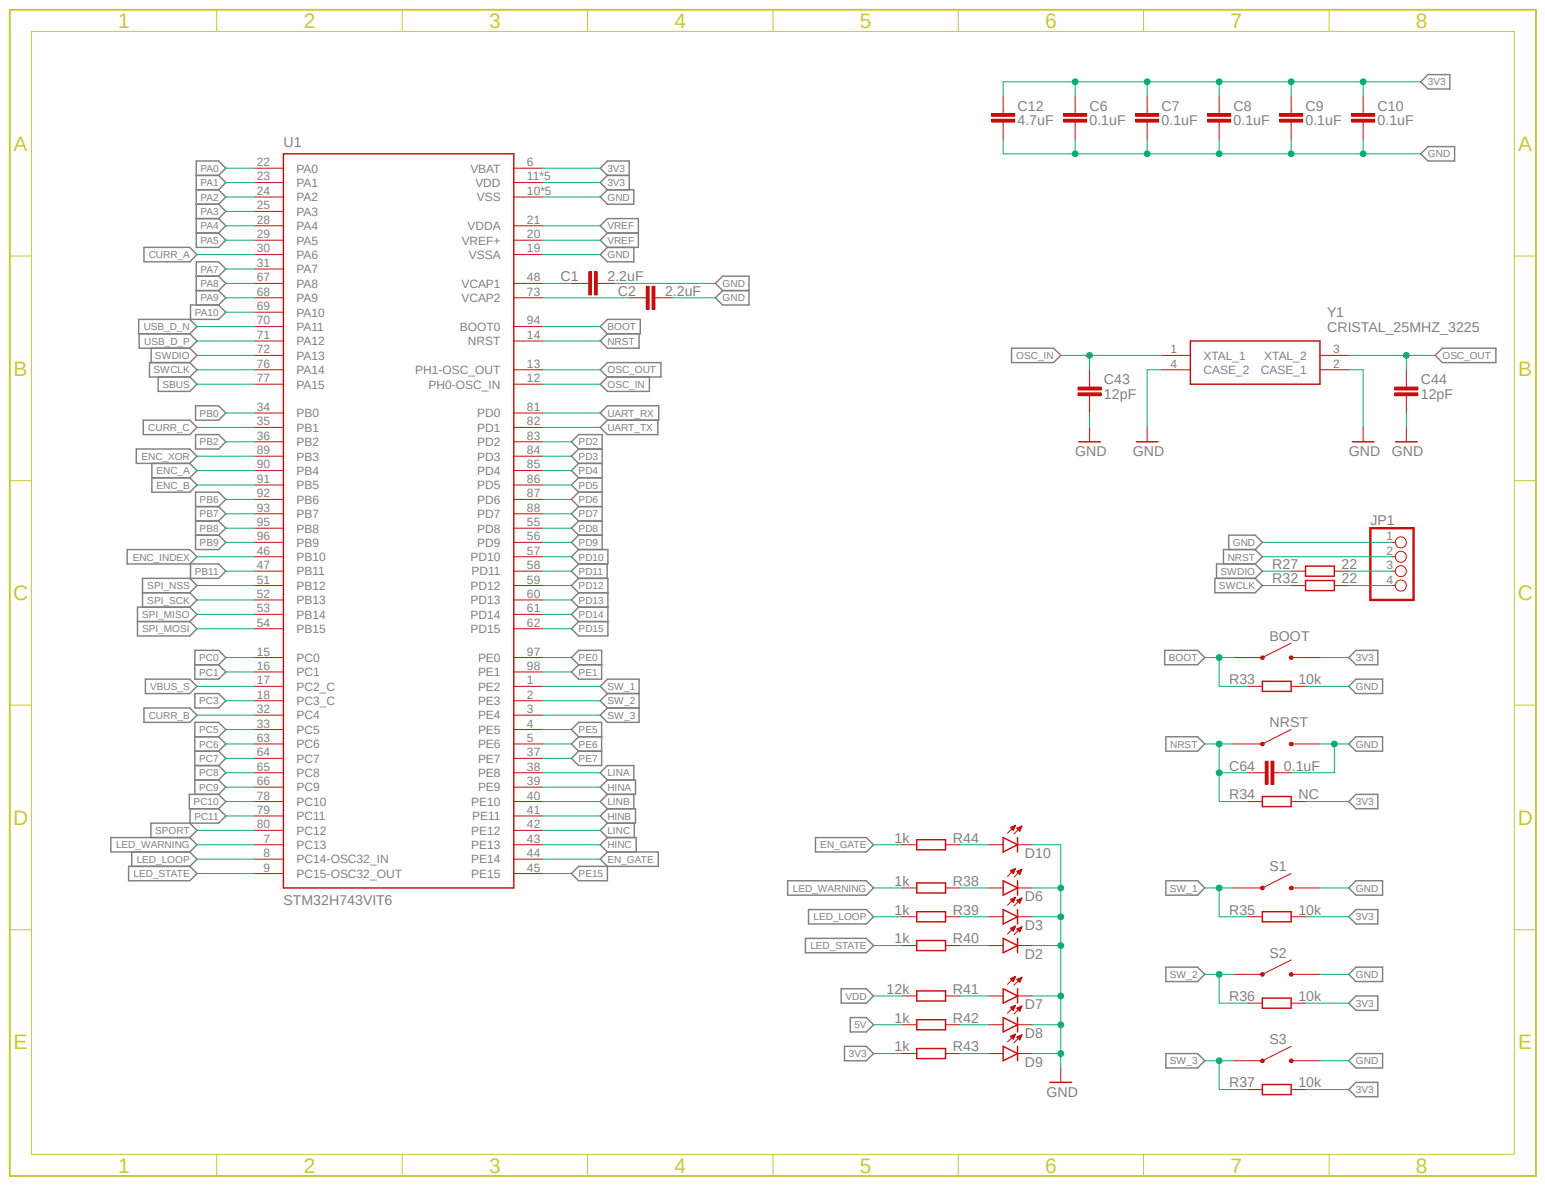
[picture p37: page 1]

CURR_B | SW_3

A

A

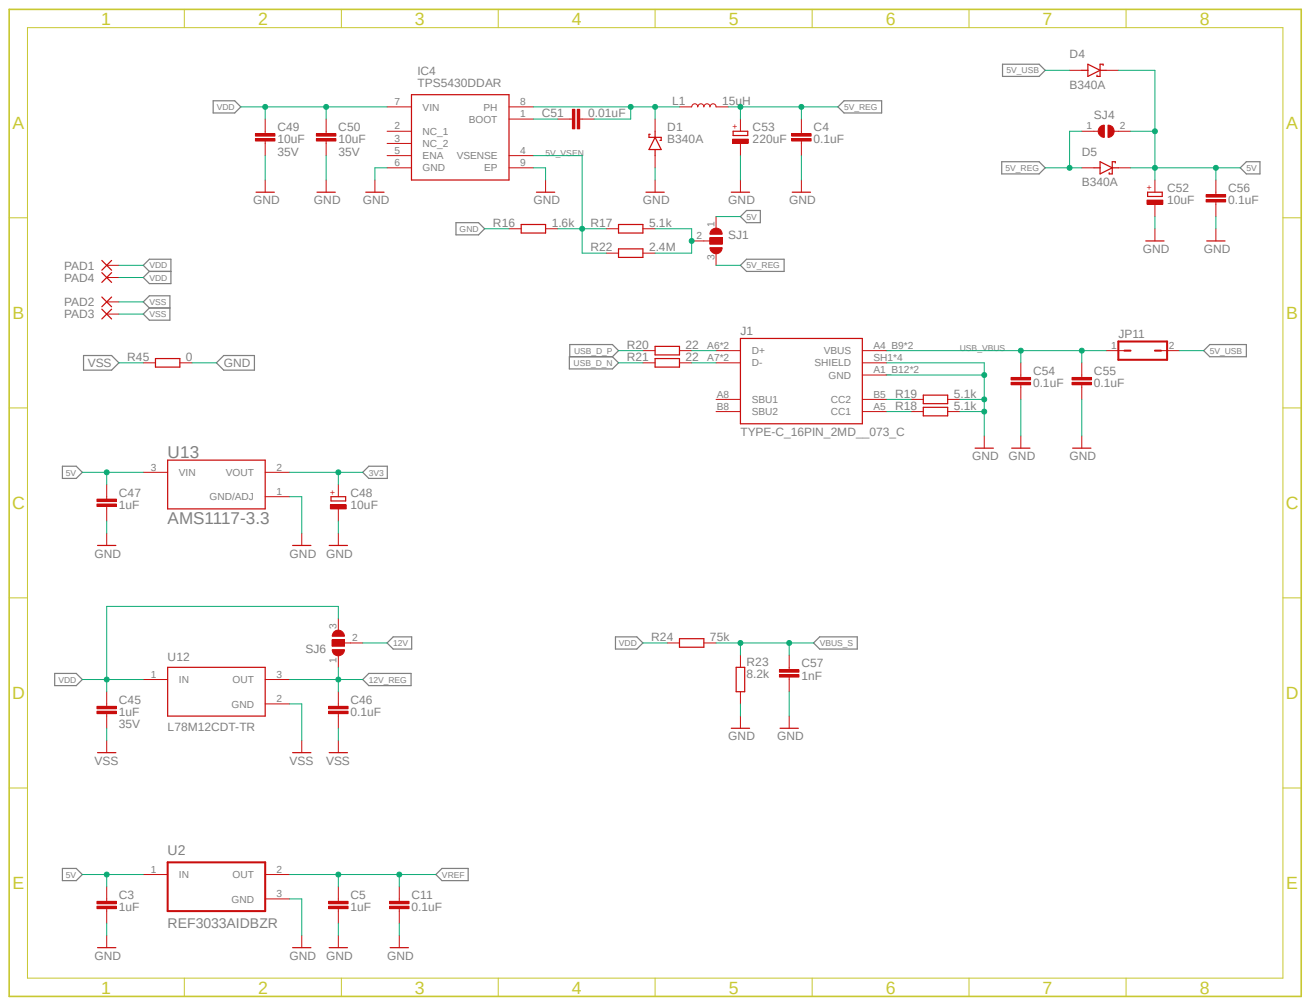
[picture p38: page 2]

ABCDE | 1 | 2 | 3 | 4 | 5 | 6 | 7 | 8 | ABCDE 1 | 2 | 3 | 4 | 5 | 6 | 7 | 8

# Osilocopio ³.3k 3.3k 3.3k

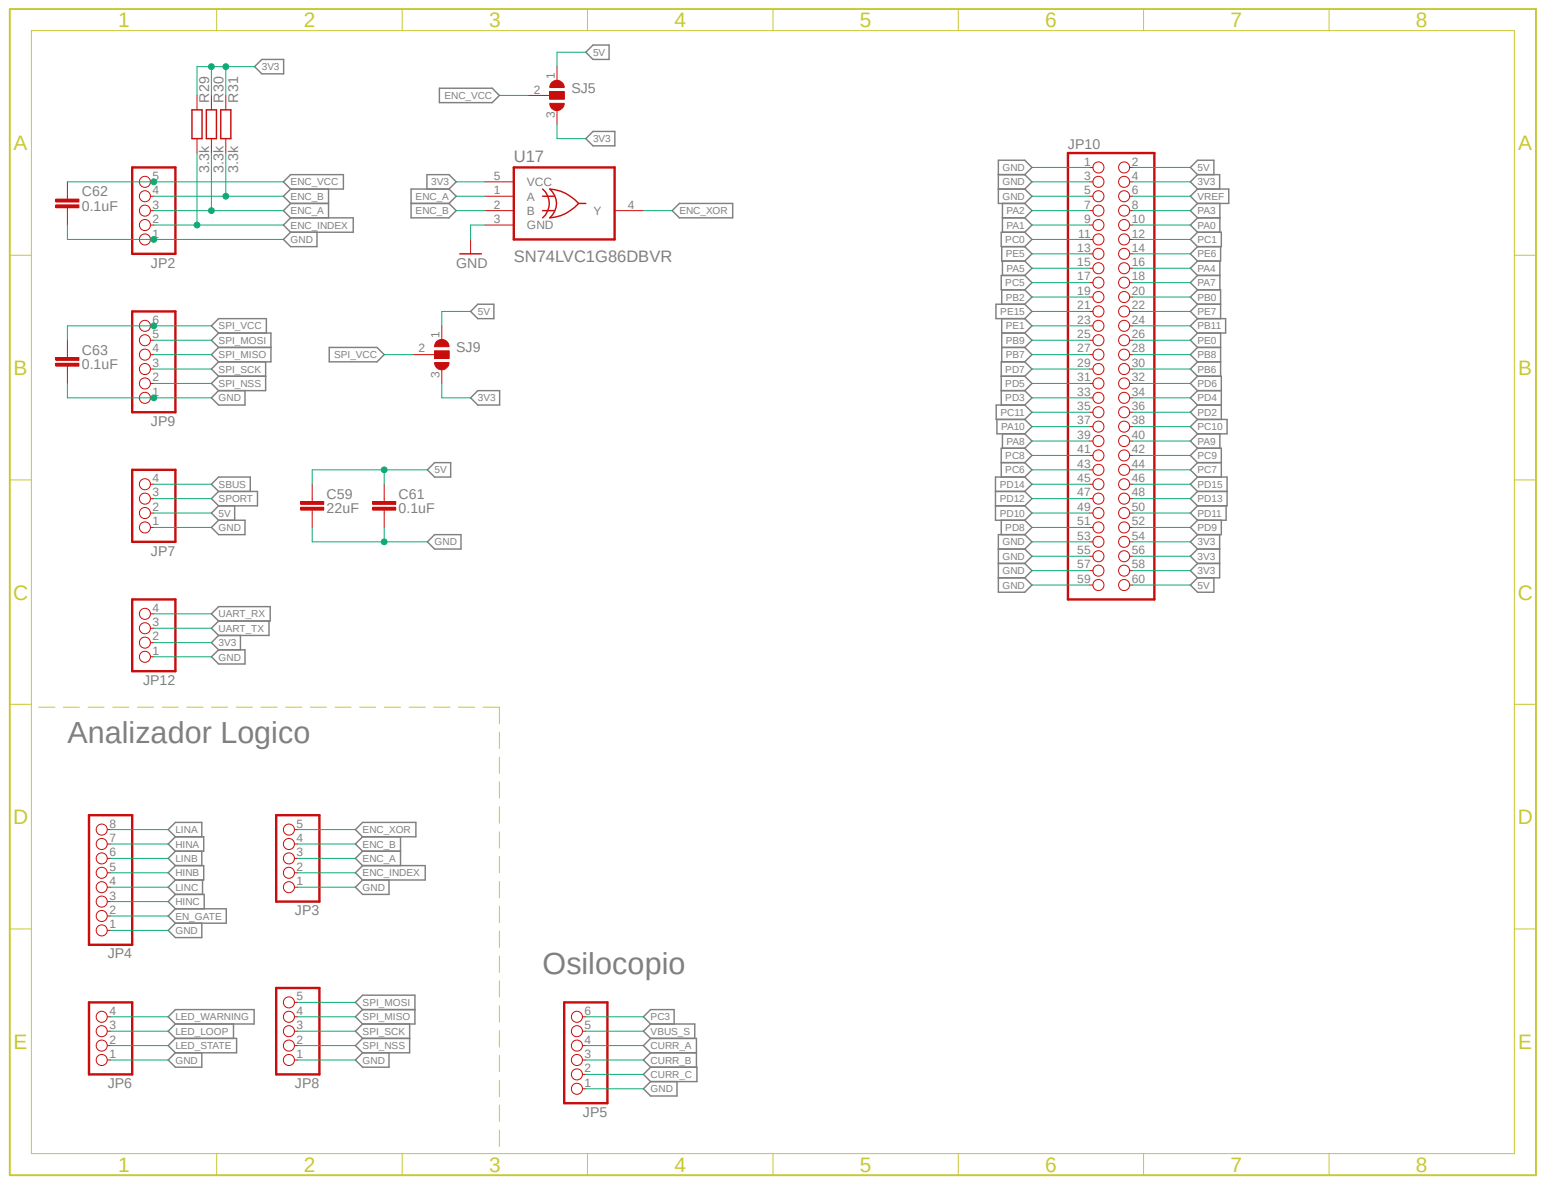
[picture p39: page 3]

ABC | 1 | 2 | 3 | 4 | 5 | 6 | 7 | 8 | ABC 1 | 2 | 3 | 4 | 5 | 6 | 7 | 8
UCC27211AQDDARQ1 | 1

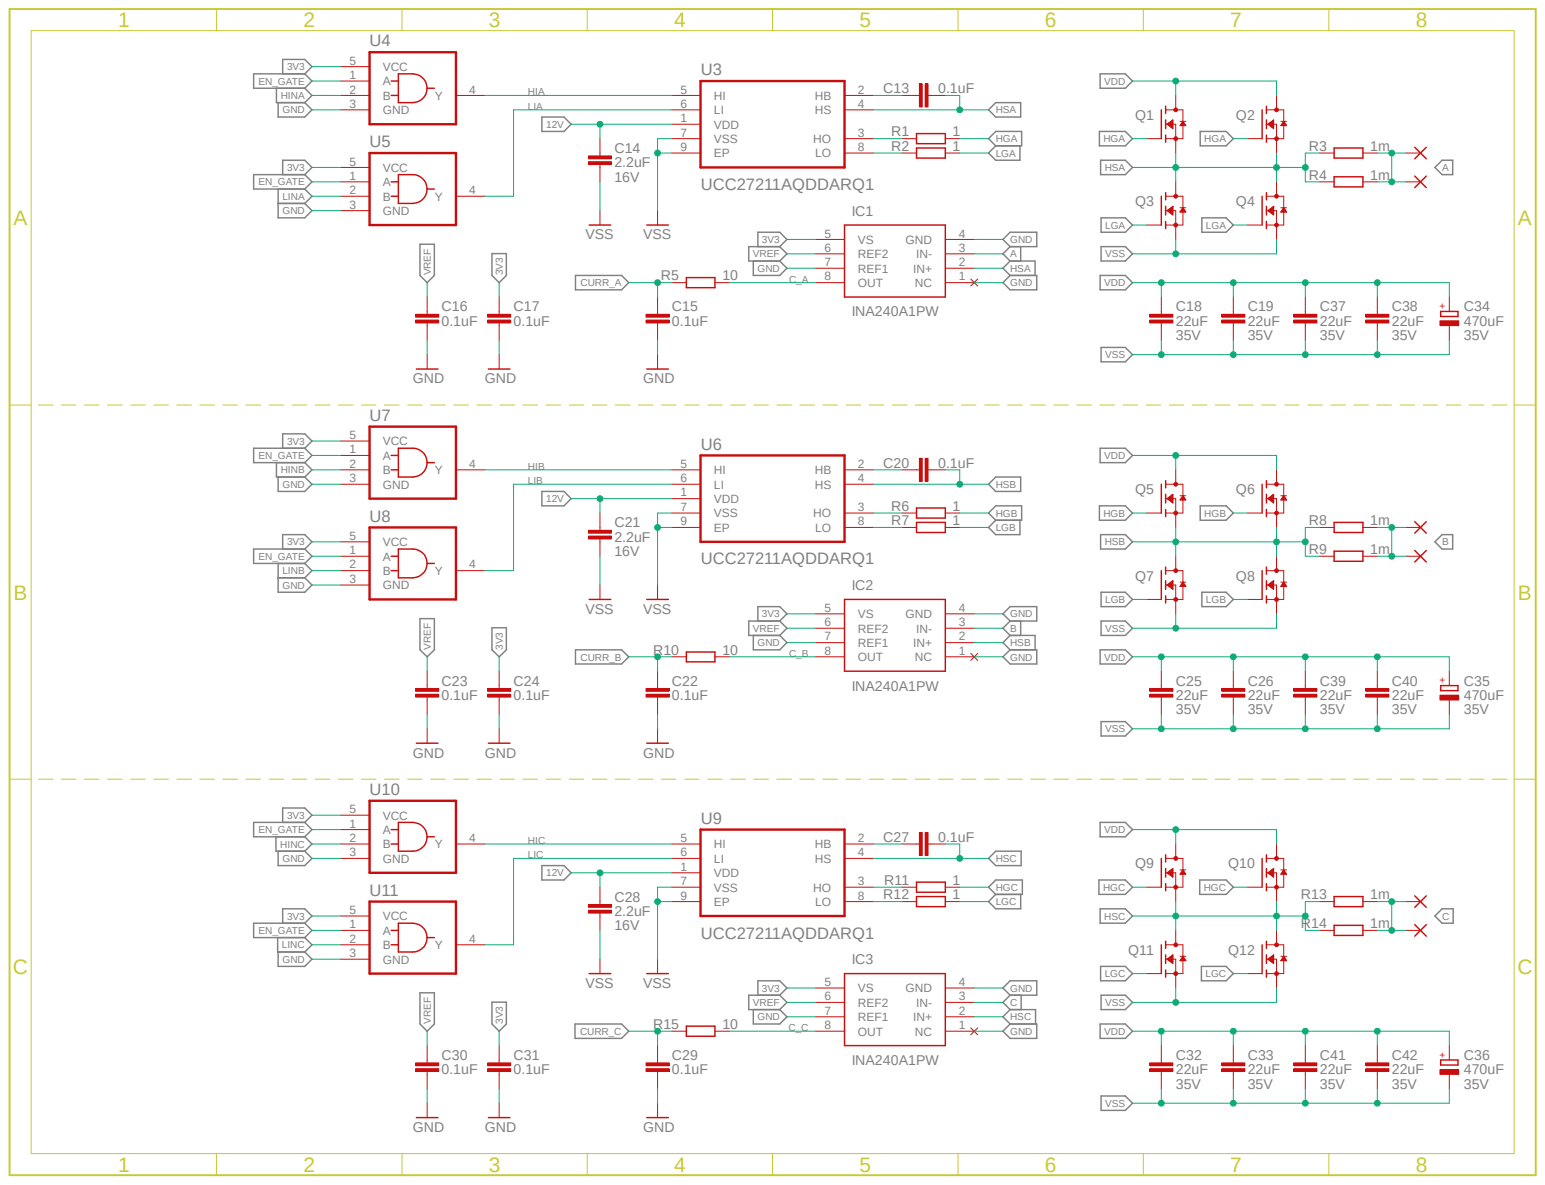
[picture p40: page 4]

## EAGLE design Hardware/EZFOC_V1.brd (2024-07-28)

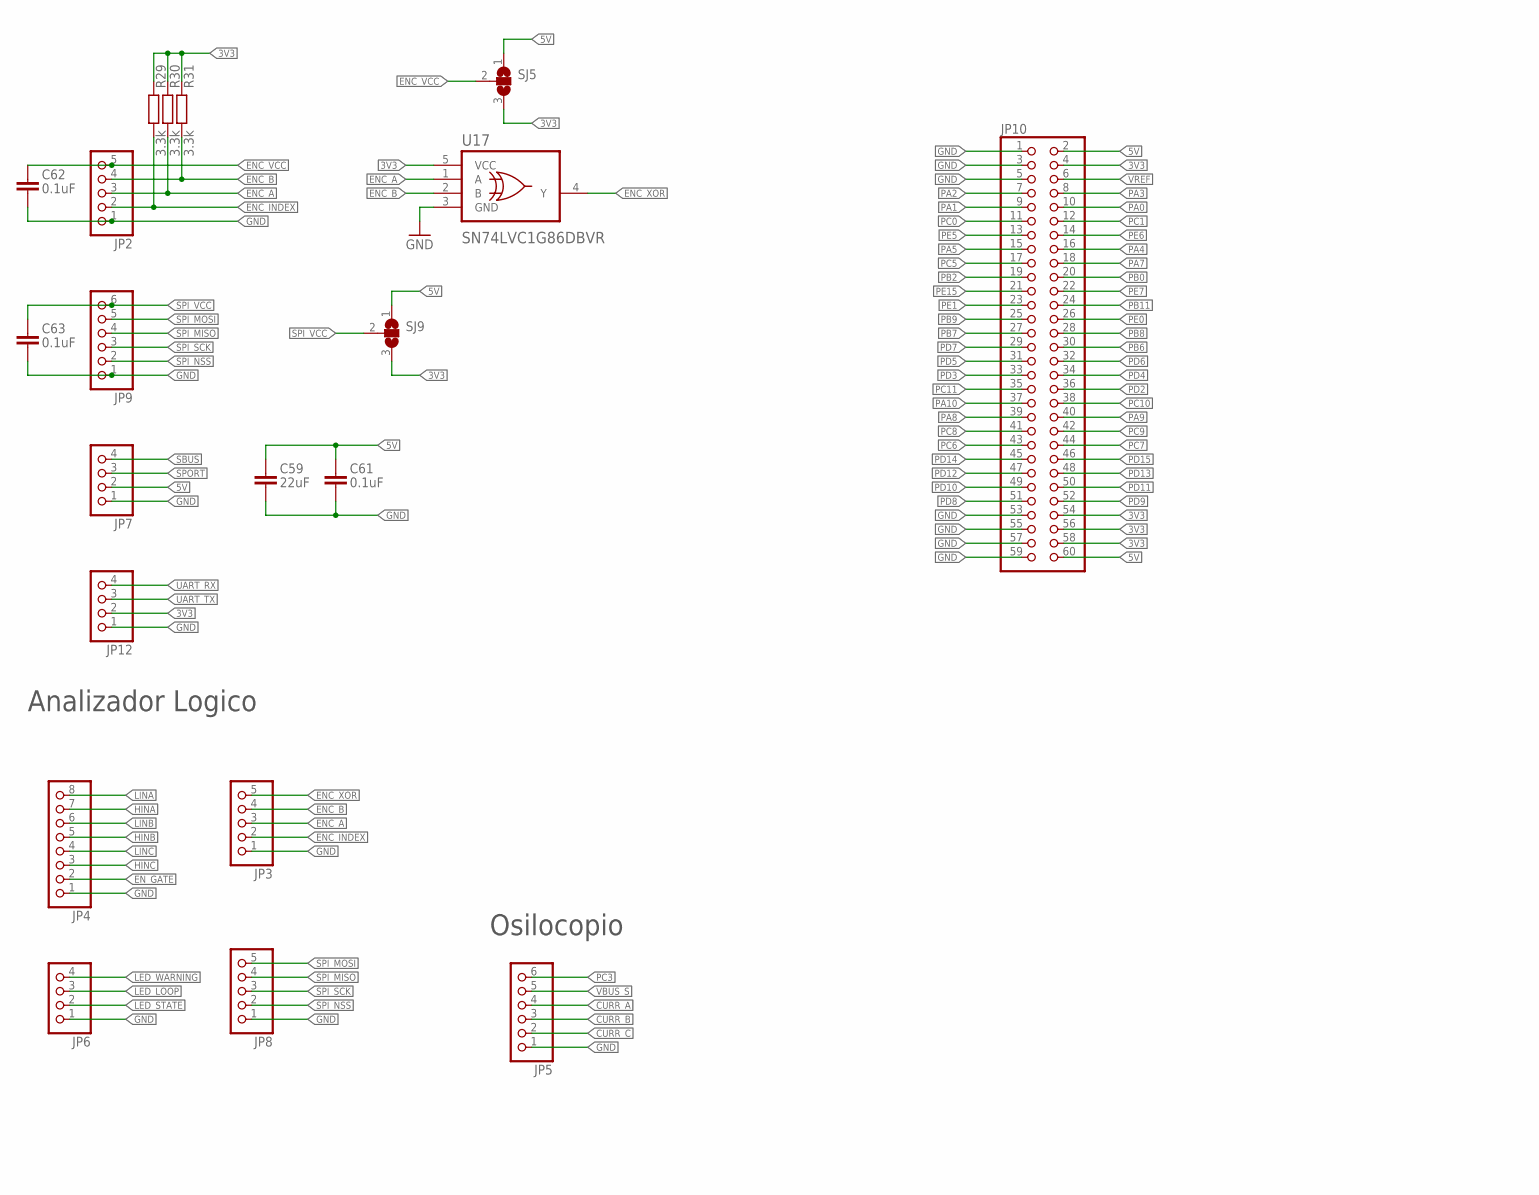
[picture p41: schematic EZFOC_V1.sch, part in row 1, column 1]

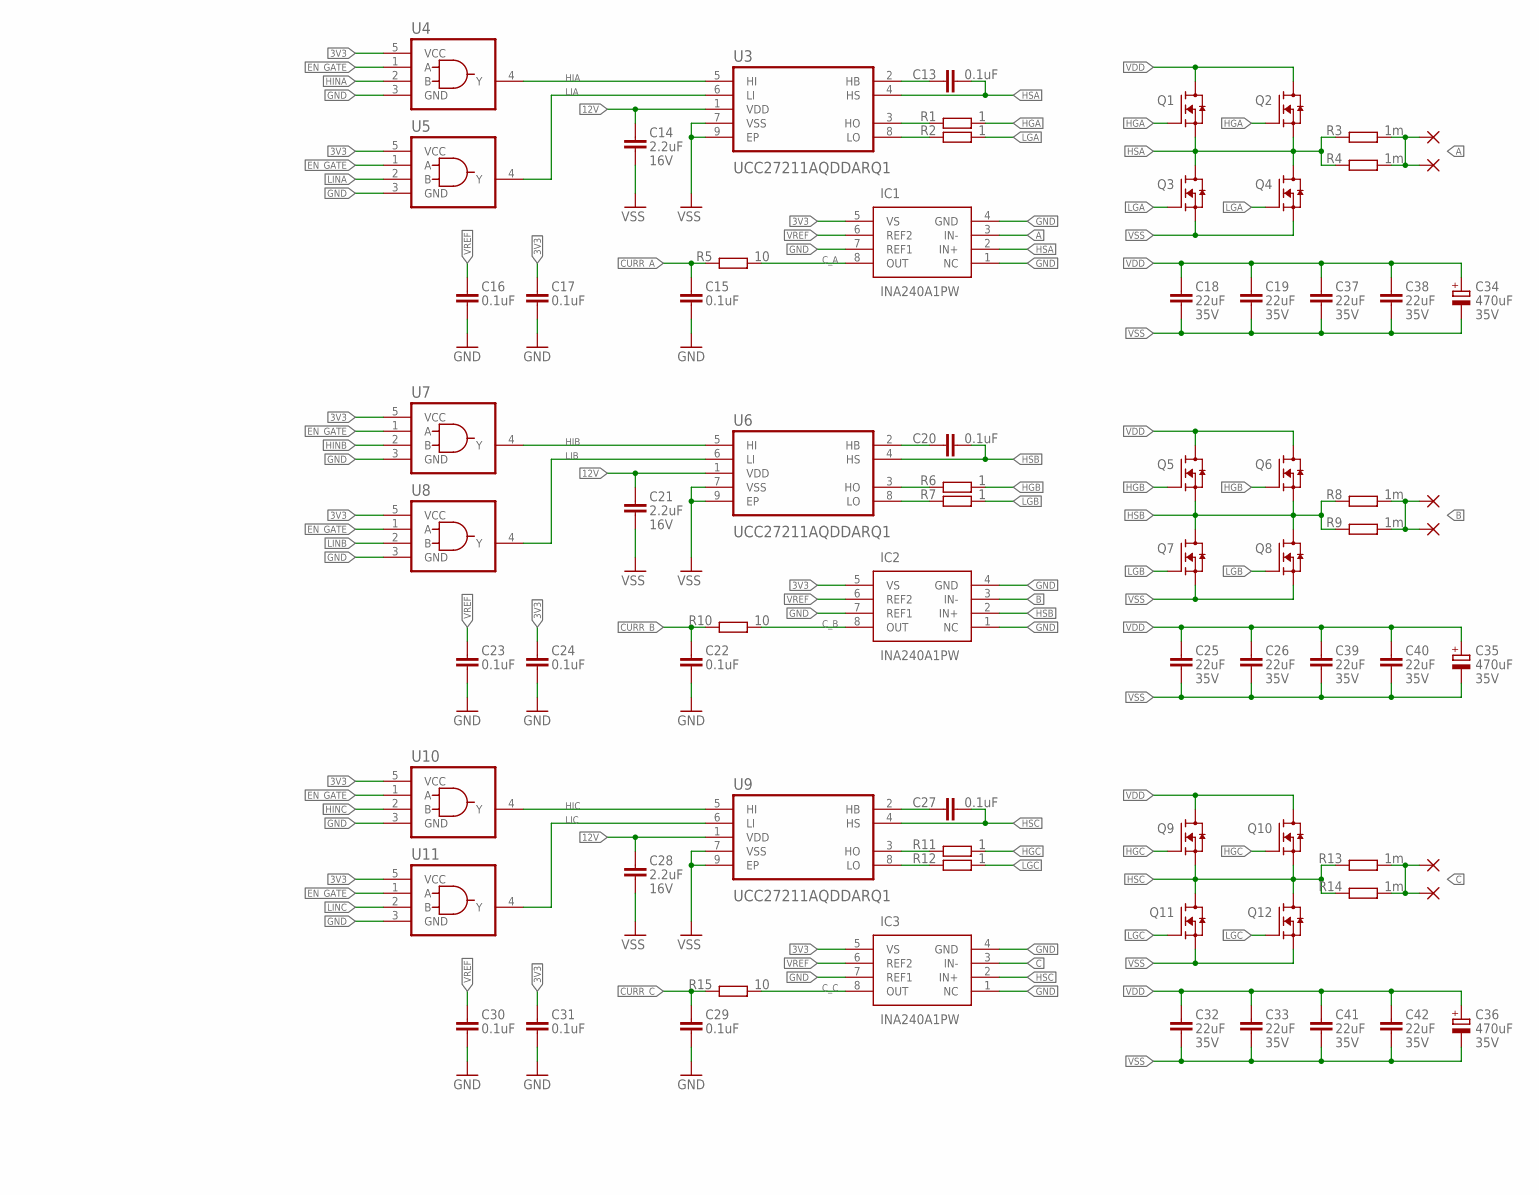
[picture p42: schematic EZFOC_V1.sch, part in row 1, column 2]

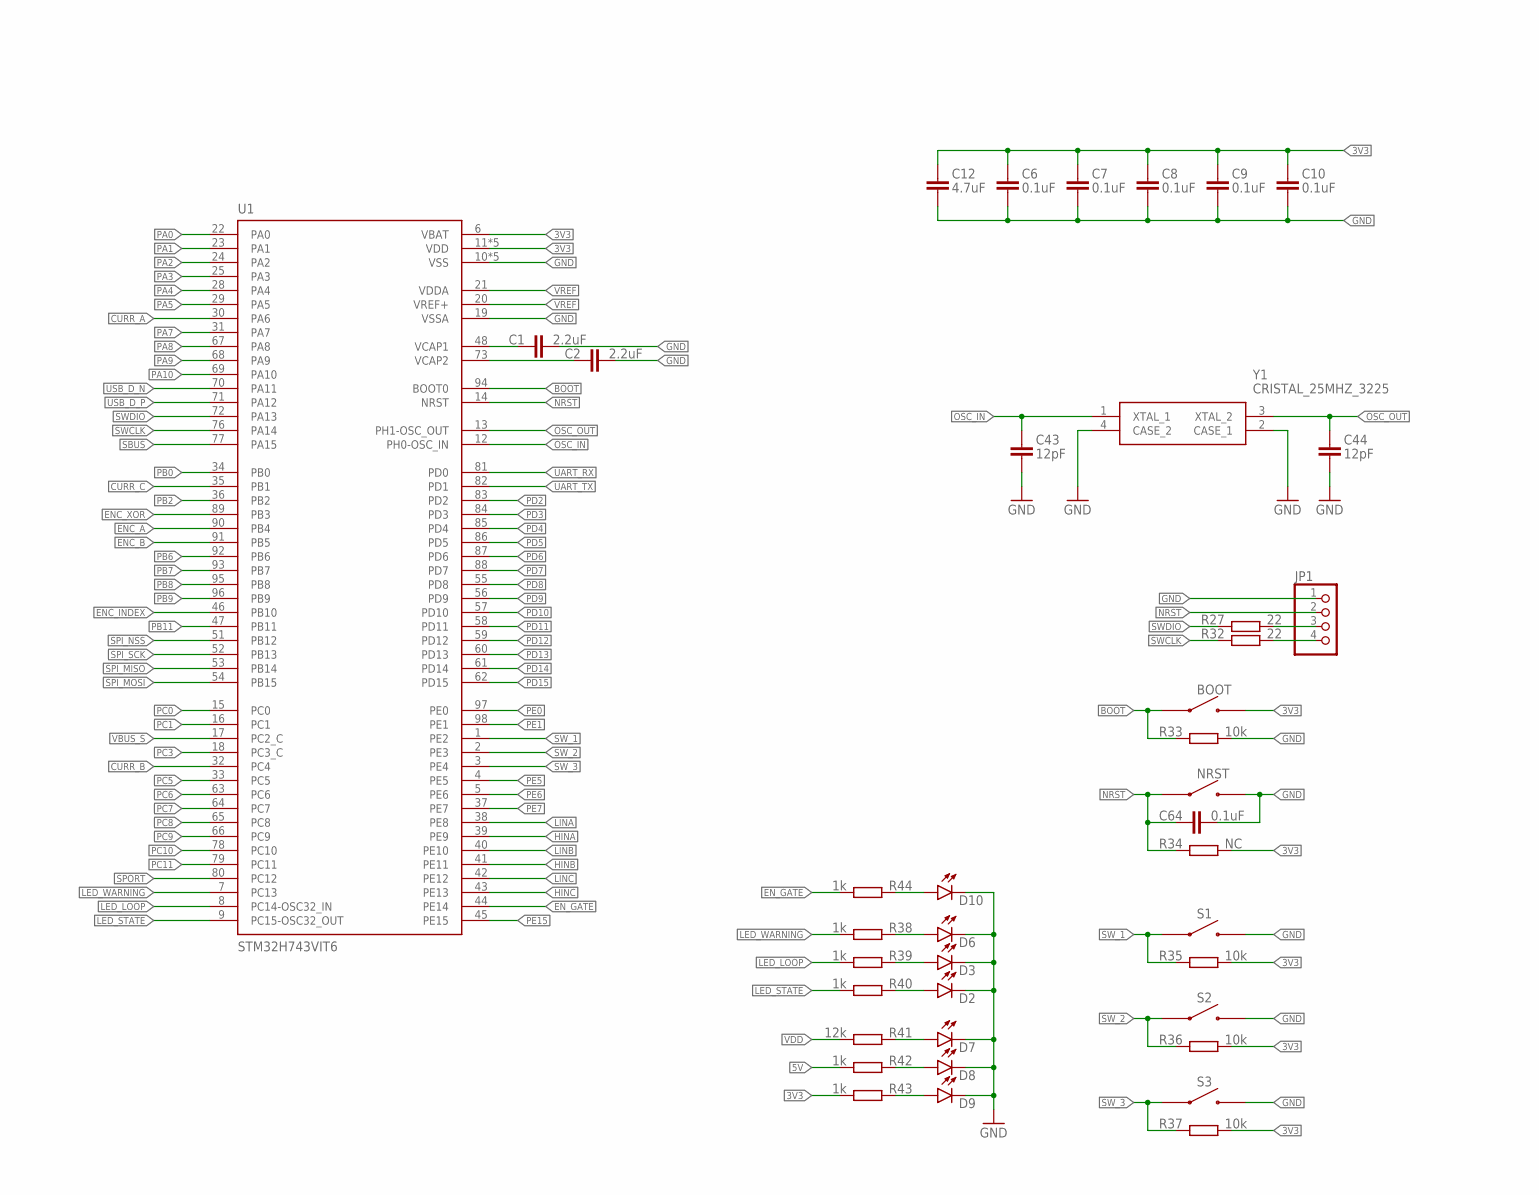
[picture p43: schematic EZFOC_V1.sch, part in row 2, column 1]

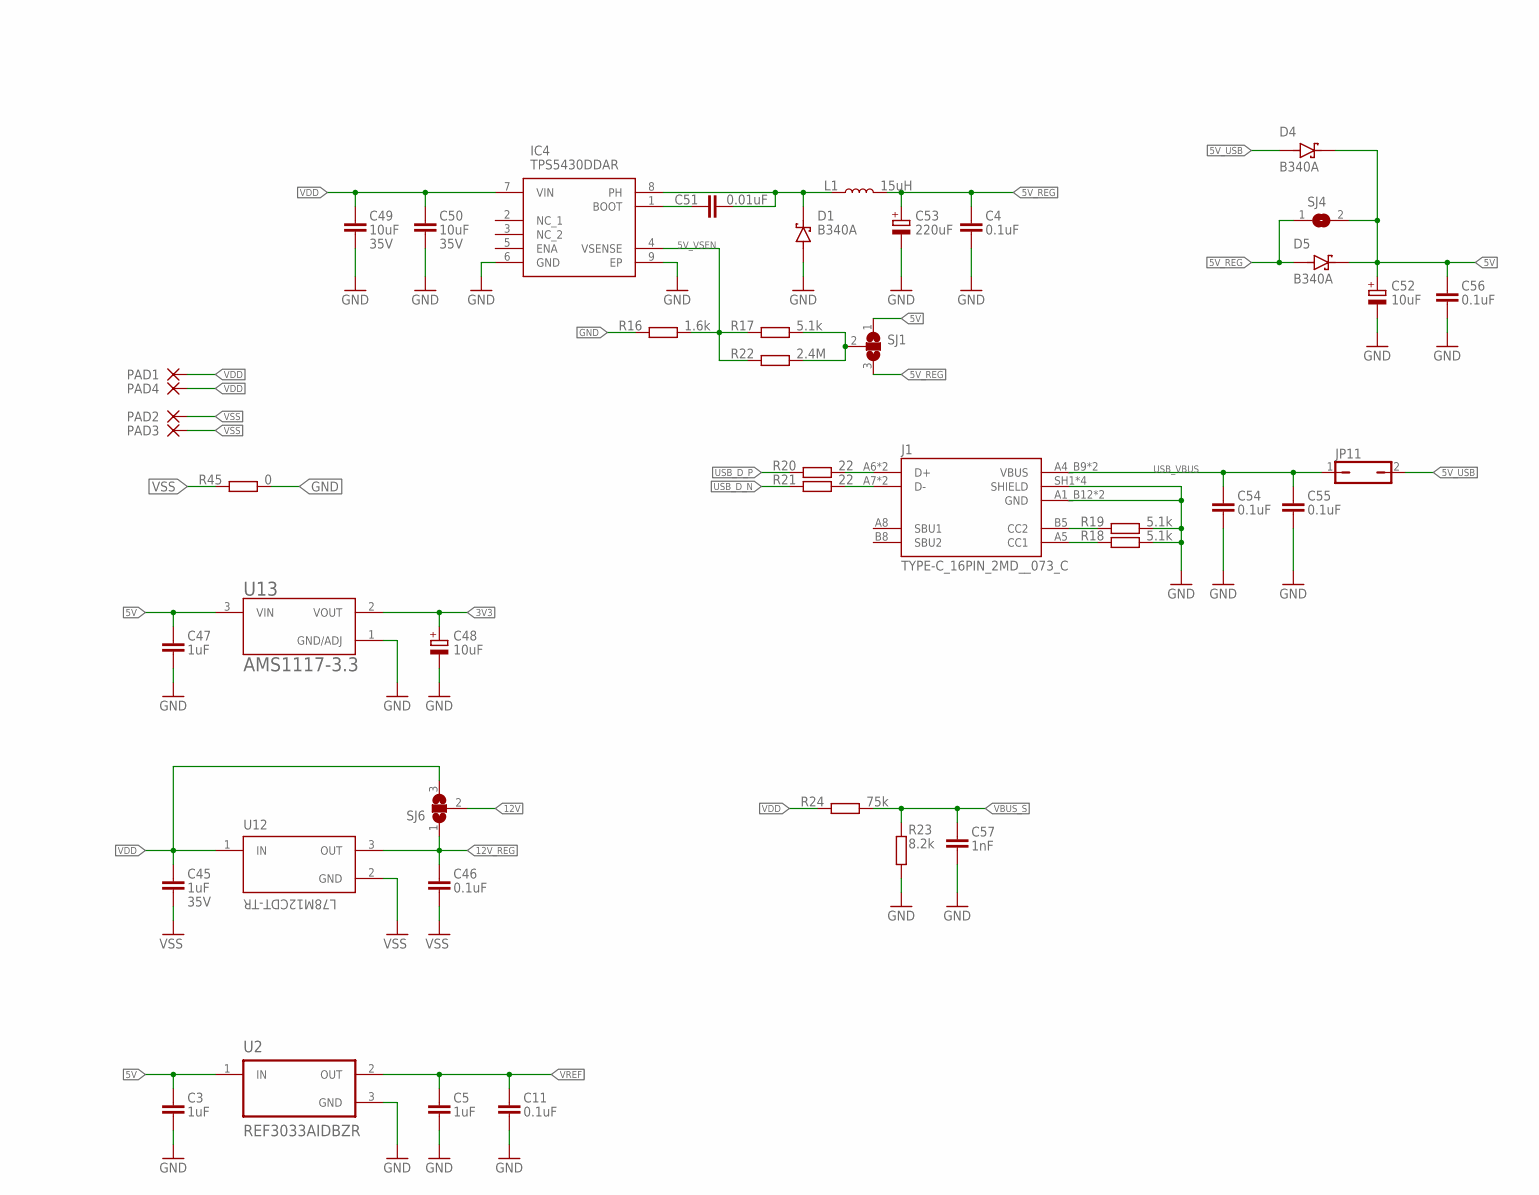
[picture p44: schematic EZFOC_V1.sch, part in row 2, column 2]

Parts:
A, A1: PAD1.27X2.54; SMD1,27-2,54
B, B1: PAD1.27X2.54; SMD1,27-2,54
BOOT: TS-1088; SKRKAEE020
C, C65: PAD1.27X2.54; SMD1,27-2,54
C1, C2: 2.2uF; 0603
C3, C5, C45, C47: 1uF; 0603; VOLTAGE_RATING 35V
C4, C6, C7, C8, C9, C10, C11, C15, C16, C17, C22, C23, C24, C29, C30, C31, C46, C54, C55, C56, C61, C62, C63, C64: 0.1uF; 0402
C12: 4.7uF; 0603
C13, C20, C27: 0.1uF; 0603; VOLTAGE_RATING 35V
C14, C21, C28: 2.2uF; 0603; VOLTAGE_RATING 16V
C18, C19, C25, C26, C32, C33, C37, C38, C39, C40, C41, C42, C59: 22uF; 1206; VOLTAGE_RATING 35V
C34, C35, C36: 470uF; CAPAE1030X1050N; VOLTAGE_RATING 35V; JLCPCB C2980172
C43, C44: 12pF; 0402
C48, C52: 10uF; CAPMP3216X180N; JLCPCB C7171
C49, C50: 10uF; 0805; VOLTAGE_RATING 35V
C51: 0.01uF; 0603
C53: 220uF; CAPAE660X800N; JLCPCB C72494
C57: 1nF; 0402
D1, D4, D5: B340A; DIOM5226X240N; JLCPCB C8678
D2, D3: LED_BLUE; LEDC2012X110N_FLAT-B; JLCPCB C965817
D6: LED_BLUE; LEDC2012X110N_FLAT-B; JLCPCB C2296
D7, D8, D9: LED_BLUE; LEDC2012X110N_FLAT-B; JLCPCB C84256
D10: LED_BLUE; LEDC2012X110N_FLAT-B; JLCPCB C2297
IC1, IC2, IC3: INA240A1PW; SOP65P640X120-8N; JLCPCB C93965
IC4: TPS5430DDAR; SOIC127P600X170-9N
J1: TYPE-C_16PIN_2MD__073_C; GCT_USB4105-GF-A
JP1, JP6, JP7, JP12: PINHD-1X4; 1X04
JP2, JP3, JP8: PINHD-1X5; 1X05
JP4: PINHD-1X8; 1X08
JP5, JP9: PINHD-1X6; 1X06
JP10: PINHD-2X30; 2X30
JP11: JP1Q; JP1
L1: 15uH; SMD6.6X7.3MM
NRST: TS-1088; SKRKAEE020
PAD1, PAD2, PAD3, PAD4: PAD2.54X5.08; SMD2,54-5,08
Q1, Q2, Q3, Q4, Q5, Q6, Q7, Q8, Q9, Q10, Q11, Q12: BSC011N03LSI_FL; TDSON-8FL
R1, R2, R6, R7, R11, R12: 1; 0603
R3, R4, R8, R9, R13, R14: 1m; 2512; JLCPCB C7370895
R5, R10, R15: 10; 0402
R16: 1.6k; 0603
R17, R18, R19: 5.1k; 0603
R20, R21, R27, R32: 22; 0402
R22: 2.4M; 0603
R23: 8.2k; 0603
R24: 75k; 0603
R29, R30, R31: 3.3k; 0402
R33, R35, R36, R37: 10k; 0402
R34: NC; 0402
R38, R39, R40, R42, R43, R44: 1k; 0402
R41: 12k; 0402
R45: 0; 1206; JLCPCB C17888
S1, S2, S3: TS-1088; SKRKAEE020
SJ1, SJ5, SJ6, SJ9: SJ2W; SJ_2
SJ4: SJ
U1: STM32H743VIT6; LQFP100
U2: REF3033AIDBZR; SOT95P237X112-3N
U3, U6, U9: UCC27211AQDDARQ1; SOIC127P600X170-9N
U4, U5, U7, U8, U10, U11: SN74LVC1G08DBVR; SOT95P280X145-5N
U12: L78M12CDT-TR; VREG_L78M12CDT-TR
U13: AMS1117-3.3; SOT229P700X180-4N
U17: SN74LVC1G86DBVR; SOT95P280X145-5N
Y1: CRISTAL_25MHZ_3225; SMD3225-4P

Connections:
3V3: BOOT.2, C6.1, C7.1, C8.1, C9.1, C10.1, C12.1, C17.1, C24.1, C31.1, C48.1 (+), IC1.5 (VS), IC2.5 (VS), IC3.5 (VS), JP10.4, JP10.54, JP10.56, JP10.58, JP12.2, R29.1, R30.1, R31.1, R34.2, R35.2, R36.2, R37.2, R43.2, SJ5.3, SJ9.3, U1.6 (VBAT), U1.11 (VDD), U1.27 (VDD), U1.50 (VDD), U1.75 (VDD), U1.100 (VDD), U4.5 (VCC), U5.5 (VCC), U7.5 (VCC), U8.5 (VCC), U10.5 (VCC), U11.5 (VCC), U13.2 (VOUT), U17.5 (VCC)
5V: C3.1, C47.1, C52.1 (+), C56.1, C59.1, C61.1, D4.C, D5.C, JP7.2, JP10.2, JP10.60, R42.2, SJ1.1, SJ4.2, SJ5.1, SJ9.1, U2.1 (IN), U13.3 (VIN)
5V_REG: C4.1, C53.1 (+), D5.A, L1.2, SJ1.3, SJ4.1
5V_USB: D4.A, JP11.2
5V_VSEN: IC4.4 (VSENSE), R16.2, R17.1, R22.1
12V: C14.1, C21.1, C28.1, SJ6.2, U3.1 (VDD), U6.1 (VDD), U9.1 (VDD)
12V_REG: C46.1, SJ6.1, U12.3 (OUT)
A: A.1, A1.1, IC1.3 (IN-), R3.2, R4.2
B: B.1, B1.1, IC2.3 (IN-), R8.2, R9.2
BOOT: BOOT.1, R33.1, U1.94 (BOOT0)
C: C.1, C65.1, IC3.3 (IN-), R13.2, R14.2
CURR_A: C15.1, JP5.4, R5.1, U1.30 (PA6)
CURR_B: C22.1, JP5.3, R10.1, U1.32 (PC4)
CURR_C: C29.1, JP5.2, R15.1, U1.35 (PB1)
C_A: IC1.8 (OUT), R5.2
C_B: IC2.8 (OUT), R10.2
C_C: IC3.8 (OUT), R15.2
ENC_A: JP2.3, JP3.3, R30.2, U1.90 (PB4), U17.1 (A)
ENC_B: JP2.4, JP3.4, R31.2, U1.91 (PB5), U17.2 (B)
ENC_INDEX: JP2.2, JP3.2, R29.2, U1.46 (PB10)
ENC_VCC: C62.1, JP2.5, SJ5.2
ENC_XOR: JP3.5, U1.89 (PB3), U17.4 (Y)
EN_GATE: JP4.2, R44.2, U1.44 (PE14), U4.1 (A), U5.1 (A), U7.1 (A), U8.1 (A), U10.1 (A), U11.1 (A)
EN_GATE_R: D10.A, R44.1
GND: C1.2, C2.2, C3.2, C4.2, C5.2, C6.2, C7.2, C8.2, C9.2, C10.2, C11.2, C12.2, C15.2, C16.2, C17.2, C22.2, C23.2, C24.2, C29.2, C30.2, C31.2, C43.2, C44.2, C47.2, C48.2 (-), C49.2, C50.2, C52.2 (-), C53.2 (-), C54.2, C55.2, C56.2, C57.2, C59.2, C61.2, C62.2, C63.2, C64.2, D1.A, D2.C, D3.C, D6.C, D7.C, D8.C, D9.C, D10.C, IC1.1 (NC), IC1.4 (GND), IC1.7 (REF1), IC2.1 (NC), IC2.4 (GND), IC2.7 (REF1), IC3.1 (NC), IC3.4 (GND), IC3.7 (REF1), IC4.6 (GND), IC4.9 (EP), J1.A1_B12 (GND), J1.B1_A12 (GND), J1.SH1 (SHIELD), J1.SH2 (SHIELD), J1.SH3 (SHIELD), J1.SH4 (SHIELD), JP1.1, JP2.1, JP3.1, JP4.1, JP5.1, JP6.1, JP7.1, JP8.1, JP9.1, JP10.1, JP10.3, JP10.5, JP10.53, JP10.55, JP10.57, JP10.59, JP12.1, NRST.2, R16.1, R18.2, R19.2, R23.1, R33.2, R45.2, S1.2, S2.2, S3.2, U1.10 (VSS), U1.19 (VSSA), U1.26 (VSS), U1.49 (VSS), U1.74 (VSS), U1.99 (VSS), U2.3 (GND), U4.3 (GND), U5.3 (GND), U7.3 (GND), U8.3 (GND), U10.3 (GND), U11.3 (GND), U13.1 (GND/ADJ), U17.3 (GND), Y1.2 (CASE_1), Y1.4 (CASE_2)
HBA: C13.1, U3.2 (HB)
HBB: C20.1, U6.2 (HB)
HBC: C27.1, U9.2 (HB)
HGA: Q1.4 (G), Q2.4 (G), R1.2
HGB: Q5.4 (G), Q6.4 (G), R6.2
HGC: Q9.4 (G), Q10.4 (G), R11.2
HIA: U3.5 (HI), U4.4 (Y)
HIB: U6.5 (HI), U7.4 (Y)
HIC: U9.5 (HI), U10.4 (Y)
HINA: JP4.7, U1.39 (PE9), U4.2 (B)
HINB: JP4.5, U1.41 (PE11), U7.2 (B)
HINC: JP4.3, U1.43 (PE13), U10.2 (B)
HOA: R1.1, U3.3 (HO)
HOB: R6.1, U6.3 (HO)
HOC: R11.1, U9.3 (HO)
HSA: C13.2, IC1.2 (IN+), Q1.1 (S), Q1.2 (S), Q1.3 (S), Q1.10 (S), Q2.1 (S), Q2.2 (S), Q2.3 (S), Q2.10 (S), Q3.5 (D), Q3.6 (D), Q3.7 (D), Q3.8 (D), Q3.9 (D), Q4.5 (D), Q4.6 (D), Q4.7 (D), Q4.8 (D), Q4.9 (D), R3.1, R4.1, U3.4 (HS)
HSB: C20.2, IC2.2 (IN+), Q5.1 (S), Q5.2 (S), Q5.3 (S), Q5.10 (S), Q6.1 (S), Q6.2 (S), Q6.3 (S), Q6.10 (S), Q7.5 (D), Q7.6 (D), Q7.7 (D), Q7.8 (D), Q7.9 (D), Q8.5 (D), Q8.6 (D), Q8.7 (D), Q8.8 (D), Q8.9 (D), R8.1, R9.1, U6.4 (HS)
HSC: C27.2, IC3.2 (IN+), Q9.1 (S), Q9.2 (S), Q9.3 (S), Q9.10 (S), Q10.1 (S), Q10.2 (S), Q10.3 (S), Q10.10 (S), Q11.5 (D), Q11.6 (D), Q11.7 (D), Q11.8 (D), Q11.9 (D), Q12.5 (D), Q12.6 (D), Q12.7 (D), Q12.8 (D), Q12.9 (D), R13.1, R14.1, U9.4 (HS)
LED1R: D6.A, R38.1
LED2R: D3.A, R39.1
LED3R: D2.A, R40.1
LED4R: D7.A, R41.1
LED5R: D8.A, R42.1
LED6R: D9.A, R43.1
LED_LOOP: JP6.3, R39.2, U1.8 (PC14-OSC32_IN)
LED_STATE: JP6.2, R40.2, U1.9 (PC15-OSC32_OUT)
LED_WARNING: JP6.4, R38.2, U1.7 (PC13)
LGA: Q3.4 (G), Q4.4 (G), R2.2
LGB: Q7.4 (G), Q8.4 (G), R7.2
LGC: Q11.4 (G), Q12.4 (G), R12.2
LIA: U3.6 (LI), U5.4 (Y)
LIB: U6.6 (LI), U8.4 (Y)
LIC: U9.6 (LI), U11.4 (Y)
LINA: JP4.8, U1.38 (PE8), U5.2 (B)
LINB: JP4.6, U1.40 (PE10), U8.2 (B)
LINC: JP4.4, U1.42 (PE12), U11.2 (B)
LOA: R2.1, U3.8 (LO)
LOB: R7.1, U6.8 (LO)
LOC: R12.1, U9.8 (LO)
NRST: C64.1, JP1.2, NRST.1, R34.1, U1.14 (NRST)
OSC_IN: C43.1, U1.12 (PH0-OSC_IN), Y1.1 (XTAL_1)
OSC_OUT: C44.1, U1.13 (PH1-OSC_OUT), Y1.3 (XTAL_2)
PA0: JP10.10, U1.22 (PA0)
PA1: JP10.9, U1.23 (PA1)
PA2: JP10.7, U1.24 (PA2)
PA3: JP10.8, U1.25 (PA3)
PA4: JP10.16, U1.28 (PA4)
PA5: JP10.15, U1.29 (PA5)
PA7: JP10.18, U1.31 (PA7)
PA8: JP10.39, U1.67 (PA8)
PA9: JP10.40, U1.68 (PA9)
PA10: JP10.37, U1.69 (PA10)
PB0: JP10.20, U1.34 (PB0)
PB2: JP10.19, U1.36 (PB2)
PB6: JP10.30, U1.92 (PB6)
PB7: JP10.27, U1.93 (PB7)
PB8: JP10.28, U1.95 (PB8)
PB9: JP10.25, U1.96 (PB9)
PB11: JP10.24, U1.47 (PB11)
PC0: JP10.11, U1.15 (PC0)
PC1: JP10.12, U1.16 (PC1)
PC3: JP5.6, U1.18 (PC3_C)
PC5: JP10.17, U1.33 (PC5)
PC6: JP10.43, U1.63 (PC6)
PC7: JP10.44, U1.64 (PC7)
PC8: JP10.41, U1.65 (PC8)
PC9: JP10.42, U1.66 (PC9)
PC10: JP10.38, U1.78 (PC10)
PC11: JP10.35, U1.79 (PC11)
PD2: JP10.36, U1.83 (PD2)
PD3: JP10.33, U1.84 (PD3)
PD4: JP10.34, U1.85 (PD4)
PD5: JP10.31, U1.86 (PD5)
PD6: JP10.32, U1.87 (PD6)
PD7: JP10.29, U1.88 (PD7)
PD8: JP10.51, U1.55 (PD8)
PD9: JP10.52, U1.56 (PD9)
PD10: JP10.49, U1.57 (PD10)
PD11: JP10.50, U1.58 (PD11)
PD12: JP10.47, U1.59 (PD12)
PD13: JP10.48, U1.60 (PD13)
PD14: JP10.45, U1.61 (PD14)
PD15: JP10.46, U1.62 (PD15)
PE0: JP10.26, U1.97 (PE0)
PE1: JP10.23, U1.98 (PE1)
PE5: JP10.13, U1.4 (PE5)
PE6: JP10.14, U1.5 (PE6)
PE7: JP10.22, U1.37 (PE7)
PE15: JP10.21, U1.45 (PE15)
REG_BOOT: C51.1, IC4.1 (BOOT)
REG_PH: C51.2, D1.C, IC4.8 (PH), L1.1
SBUS: JP7.4, U1.77 (PA15)
SJ1_SEL: R17.2, R22.2, SJ1.2
SPI_MISO: JP8.4, JP9.4, U1.53 (PB14)
SPI_MOSI: JP8.5, JP9.5, U1.54 (PB15)
SPI_NSS: JP8.2, JP9.2, U1.51 (PB12)
SPI_SCK: JP8.3, JP9.3, U1.52 (PB13)
SPI_VCC: C63.1, JP9.6, SJ9.2
SPORT: JP7.3, U1.80 (PC12)
SWCLK: R32.1, U1.76 (PA14)
SWCLK_R: JP1.4, R32.2
SWDIO: R27.1, U1.72 (PA13)
SWDIO_R: JP1.3, R27.2
SW_1: R35.1, S1.1, U1.1 (PE2)
SW_2: R36.1, S2.1, U1.2 (PE3)
SW_3: R37.1, S3.1, U1.3 (PE4)
UART_RX: JP12.4, U1.81 (PD0)
UART_TX: JP12.3, U1.82 (PD1)
USB_CC1: J1.B5 (CC2), R19.1
USB_CC2: J1.A5 (CC1), R18.1
USB_DN_R: J1.A7 (D-), J1.B7 (D-), R21.2
USB_DP_R: J1.A6 (D+), J1.B6 (D+), R20.2
USB_D_N: R21.1, U1.70 (PA11)
USB_D_P: R20.1, U1.71 (PA12)
USB_VBUS: C54.1, C55.1, J1.A4_B9 (VBUS), J1.B4_A9 (VBUS), JP11.1
VBUS_S: C57.1, JP5.5, R23.2, R24.2, U1.17 (PC2_C)
VCAP1: C1.1, U1.48 (VCAP1)
VCAP2: C2.1, U1.73 (VCAP2)
VDD: C18.1, C19.1, C25.1, C26.1, C32.1, C33.1, C34.1 (+), C35.1 (+), C36.1 (+), C37.1, C38.1, C39.1, C40.1, C41.1, C42.1, C45.1, C49.1, C50.1, IC4.7 (VIN), PAD1.1, PAD4.1, Q1.5 (D), Q1.6 (D), Q1.7 (D), Q1.8 (D), Q1.9 (D), Q2.5 (D), Q2.6 (D), Q2.7 (D), Q2.8 (D), Q2.9 (D), Q5.5 (D), Q5.6 (D), Q5.7 (D), Q5.8 (D), Q5.9 (D), Q6.5 (D), Q6.6 (D), Q6.7 (D), Q6.8 (D), Q6.9 (D), Q9.5 (D), Q9.6 (D), Q9.7 (D), Q9.8 (D), Q9.9 (D), Q10.5 (D), Q10.6 (D), Q10.7 (D), Q10.8 (D), Q10.9 (D), R24.1, R41.2, SJ6.3, U12.1 (IN)
VREF: C5.1, C11.1, C16.1, C23.1, C30.1, IC1.6 (REF2), IC2.6 (REF2), IC3.6 (REF2), JP10.6, U1.20 (VREF+), U1.21 (VDDA), U2.2 (OUT)
VSS: C14.2, C18.2, C19.2, C21.2, C25.2, C26.2, C28.2, C32.2, C33.2, C34.2 (-), C35.2 (-), C36.2 (-), C37.2, C38.2, C39.2, C40.2, C41.2, C42.2, C45.2, C46.2, PAD2.1, PAD3.1, Q3.1 (S), Q3.2 (S), Q3.3 (S), Q3.10 (S), Q4.1 (S), Q4.2 (S), Q4.3 (S), Q4.10 (S), Q7.1 (S), Q7.2 (S), Q7.3 (S), Q7.10 (S), Q8.1 (S), Q8.2 (S), Q8.3 (S), Q8.10 (S), Q11.1 (S), Q11.2 (S), Q11.3 (S), Q11.10 (S), Q12.1 (S), Q12.2 (S), Q12.3 (S), Q12.10 (S), R45.1, U3.7 (VSS), U3.9 (EP), U6.7 (VSS), U6.9 (EP), U9.7 (VSS), U9.9 (EP), U12.2 (GND)

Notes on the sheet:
Analizador Logico
Osilocopio

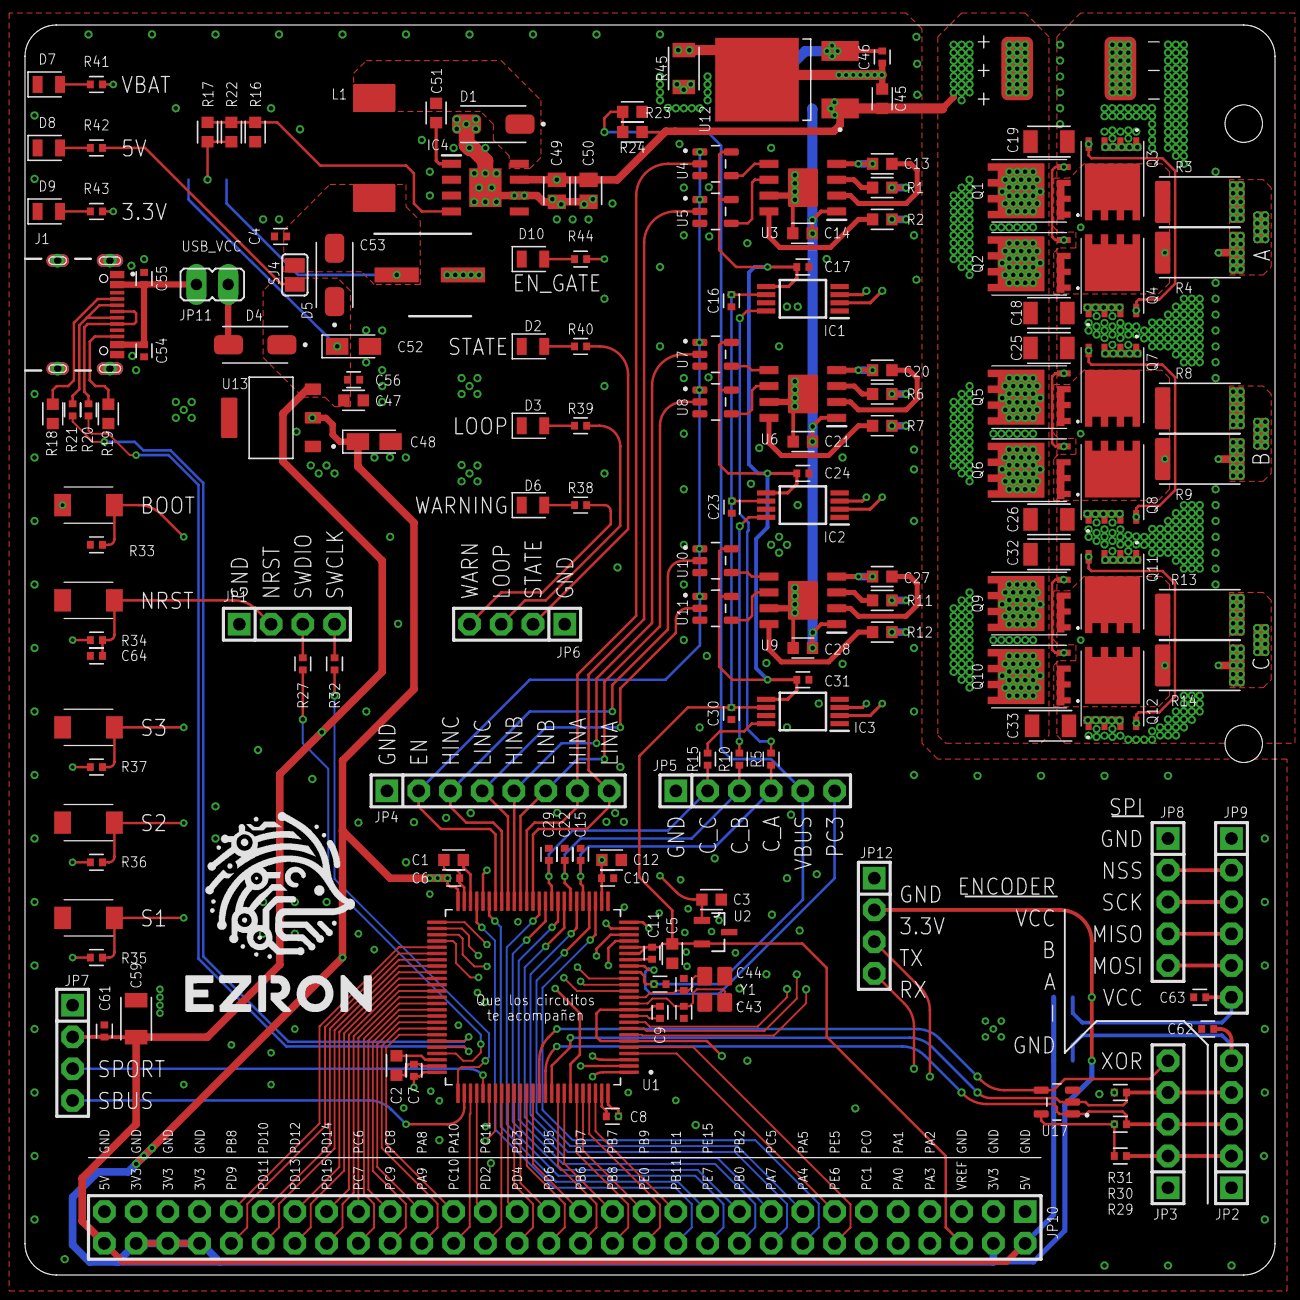
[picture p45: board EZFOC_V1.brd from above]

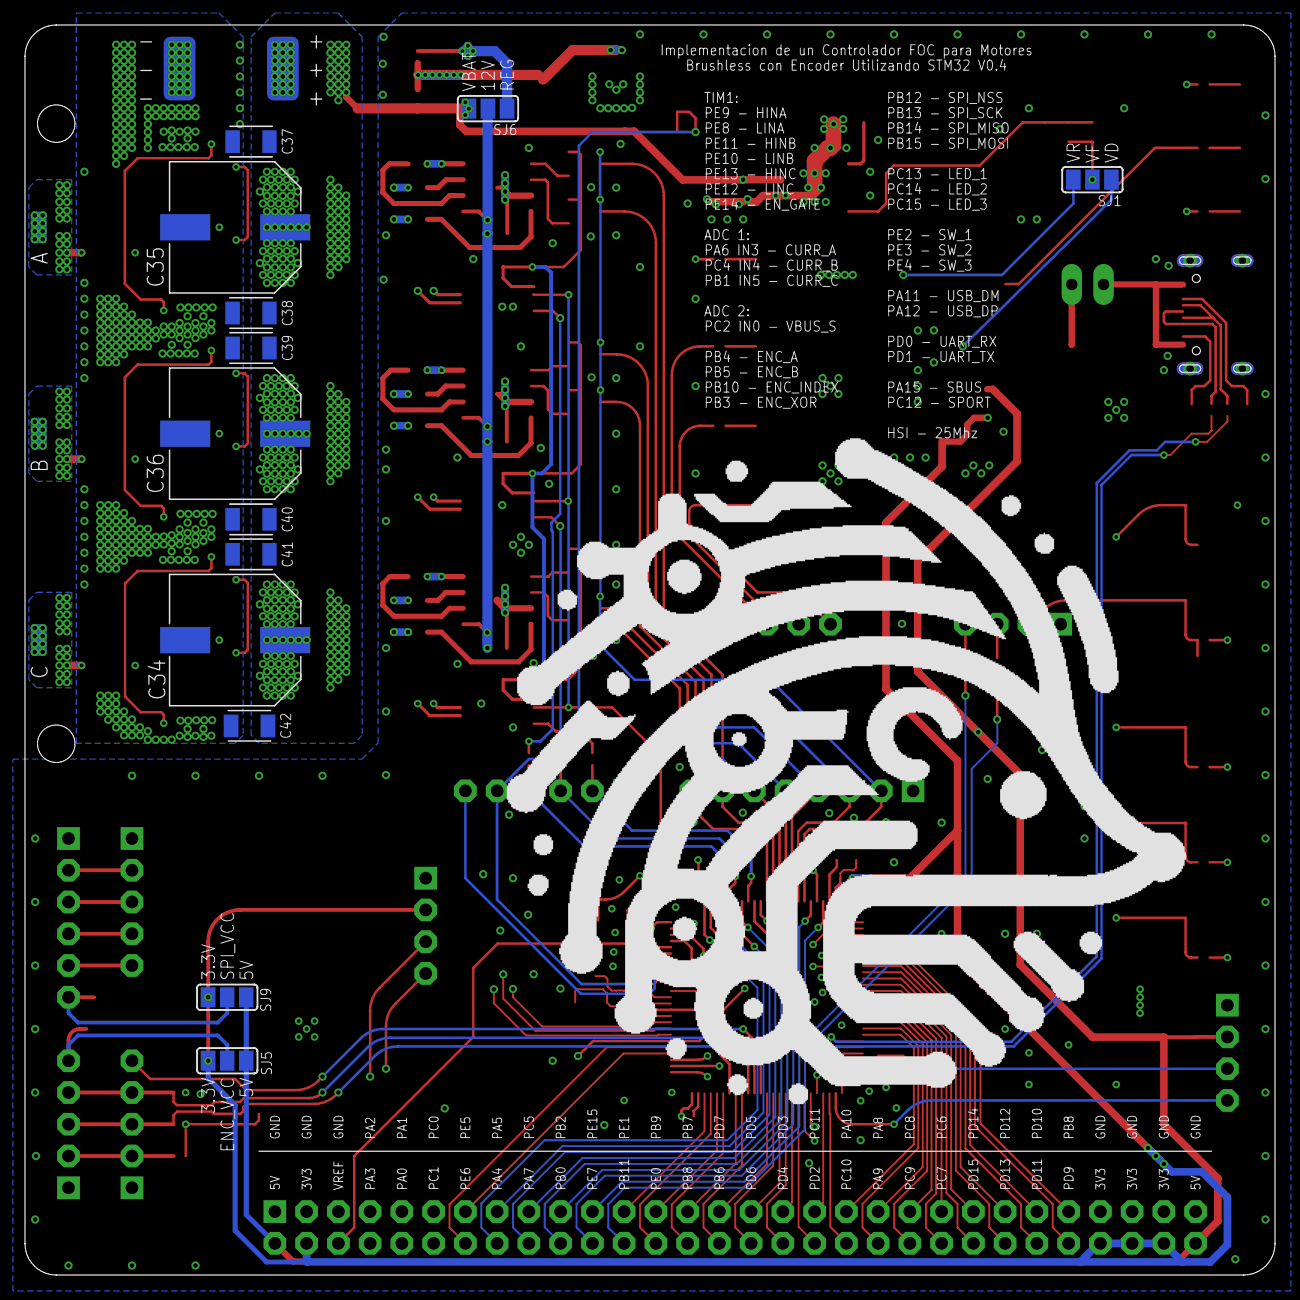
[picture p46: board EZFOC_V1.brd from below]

Board: 4 copper layers, 100.0 x 100.0 mm, 179 parts (18 on the bottom side), 146 nets.

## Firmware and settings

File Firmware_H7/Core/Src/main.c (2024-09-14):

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
/* Includes ------------------------------------------------------------------*/
#include "main.h"
#include "adc.h"
#include "bdma.h"
#include "dma.h"
#include "memorymap.h"
#include "spi.h"
#include "tim.h"
#include "usart.h"
#include "usb_device.h"
#include "gpio.h"

/* USER CODE BEGIN Includes */
#include <stdio.h>
#include <stdint.h>

#include "usbd_cdc_if.h"
#include "arm_math.h"

#include "state_machine.h"

#include "board.h"
#include "util.h"
#include "FOC.h"
#include "PID.h"
#include "debug.h"

#include "encoder.h"
#include "current.h"

/* USER CODE END Includes */


/* USER CODE BEGIN PV */

SM_t SM = {0};
tick_t TIMER_TICK = {0};
EncoderSystem ENCODER = {0};
CurrentSystem CURRENT = {0};
float Ibus;

ControllerDQ_t CURRENT_CONTROLLER = {0};
PIController_t VELOCITY_CONTROLLER = {0};
// PIDController_t VELOCITY_CONTROLLER = {0};

SVM_data_t SVM = {0};
bool PWM_EN = false;

uint16_t ADC2_DMA[ADC2_DMA_SAMPLES] __ATTR_RAM_D2 = {0};
uint16_t ADC3_DMA[ADC3_DMA_SAMPLES] __ATTR_RAM_D3 = {0};

ADCSystem ADC_VBUS = {0};
float Vbus;

ADCSystem ADC_POT_A = {0};
float POT_A = 0.0f;

ADCSystem ADC_POT_B = {0};
float POT_B = 0.0f;

ADCSystem ADC_POT_C = {0};
float POT_C = 0.0f;

ButtonDebounce_t SW1 = {0};
ButtonDebounce_t SW2 = {0};
ButtonDebounce_t SW3 = {0};

#ifdef EN_DEBUG
debug_data_t debug_data __ATTR_RAM_D1 = {0};
#endif

extern USBD_HandleTypeDef hUsbDeviceFS;
/* USER CODE END PV */

void SystemClock_Config(void);
void PeriphCommonClock_Config(void);
static void MPU_Config(void);
/* USER CODE BEGIN PFP */
void Enable_TIM1_PWM(void);
void Disable_TIM1_PWM(void);
void SM_force_stop(void);
uint8_t USB_Is_Connected(void);
/* USER CODE END PFP */

/**
  * @brief  The application entry point.
  * @retval int
  */
int main(void)
{

  /* MPU Configuration--------------------------------------------------------*/
  MPU_Config();

  /* Enable the CPU Cache */

  /* Enable I-Cache---------------------------------------------------------*/
  SCB_EnableICache();

  /* Enable D-Cache---------------------------------------------------------*/
  SCB_EnableDCache();

  /* MCU Configuration--------------------------------------------------------*/

  /* Reset of all peripherals, Initializes the Flash interface and the Systick. */
  HAL_Init();

  /* Configure the system clock */
  SystemClock_Config();

  /* Configure the peripherals common clocks */
  PeriphCommonClock_Config();

  /* Initialize all configured peripherals */
  MX_GPIO_Init();
  MX_BDMA_Init();
  MX_DMA_Init();
  MX_TIM1_Init();
  MX_TIM2_Init();
  MX_TIM3_Init();
  MX_ADC1_Init();
  MX_USB_DEVICE_Init();
  MX_ADC3_Init();
  MX_TIM15_Init();
  MX_SPI2_Init();
  MX_UART4_Init();
  MX_UART5_Init();
  MX_UART7_Init();
  MX_ADC2_Init();
  /* USER CODE BEGIN 2 */
  if (USB_Is_Connected())
  {
    HAL_Delay(1000);
    printf("INICIO de configuracion\n");
  }

  setup_ADC(&ADC_VBUS, VBUS_CTO * ADC_VREF, 0.0f, 1000.0f);

  setup_ADC(&ADC_POT_A, 2.0f, 0.5f, 10.0f);
  setup_ADC(&ADC_POT_B, 2.0f, 0.5f, 10.0f);
  setup_ADC(&ADC_POT_C, 2.0f, 0.5f, 10.0f);

  calculate_alpha((float)TIMER_IT_FREC, 8000.0f, &ENCODER.filter_global_theta);
  calculate_alpha((float)TIMER_IT_FREC, 500.0f, &ENCODER.filter_speed);
  calculate_alpha((float)TIMER_IT_FREC, 8000.0f, &ENCODER.filter_acceleration);

  calculate_alpha((float)TIMER_IT_FREC, (float)CURRENT_FILTER_CUT_FREC, &CURRENT.phase_A.filter);
  calculate_alpha((float)TIMER_IT_FREC, (float)CURRENT_FILTER_CUT_FREC, &CURRENT.phase_B.filter);
  calculate_alpha((float)TIMER_IT_FREC, (float)CURRENT_FILTER_CUT_FREC, &CURRENT.phase_C.filter);

  calculate_alpha((float)TIMER_IT_FREC, (float)CURRENT_FILTER_CUT_FREC, &CURRENT.filter_alpha);
  calculate_alpha((float)TIMER_IT_FREC, (float)CURRENT_FILTER_CUT_FREC, &CURRENT.filter_beta);

  calculate_alpha((float)TIMER_IT_FREC, 800.0f, &CURRENT.filter_d);
  calculate_alpha((float)TIMER_IT_FREC, 800.0f, &CURRENT.filter_q);

  calculate_alpha((float)TIMER_IT_FREC, 8000.0f, &CURRENT.filter_bus);

  SetupControllerDQ(&CURRENT_CONTROLLER, CURRENT_P_GAIN, CURRENT_I_GAIN);
  SetupPIController(&VELOCITY_CONTROLLER, VELOCITY_P_GAIN, VELOCITY_I_GAIN);
  // SetupPIDController(&VELOCITY_CONTROLLER, VELOCITY_P_GAIN, VELOCITY_I_GAIN,VELOCITY_D_GAIN);

  InitButtonDebounce(&SW1, &TIMER_TICK, SW_1_GPIO_Port, SW_1_Pin, ONE_MS_TICK * 20);
  InitButtonDebounce(&SW2, &TIMER_TICK, SW_2_GPIO_Port, SW_2_Pin, ONE_MS_TICK * 20);
  InitButtonDebounce(&SW3, &TIMER_TICK, SW_3_GPIO_Port, SW_3_Pin, ONE_MS_TICK * 20);

  Disable_TIM1_PWM();

  HAL_TIM_PWM_Start(&htim1, TIM_CHANNEL_1);
  HAL_TIMEx_PWMN_Start(&htim1, TIM_CHANNEL_1);
  HAL_TIM_PWM_Start(&htim1, TIM_CHANNEL_2);
  HAL_TIMEx_PWMN_Start(&htim1, TIM_CHANNEL_2);
  HAL_TIM_PWM_Start(&htim1, TIM_CHANNEL_3);
  HAL_TIMEx_PWMN_Start(&htim1, TIM_CHANNEL_3);

  HAL_GPIO_WritePin(EN_GATE_GPIO_Port, EN_GATE_Pin, GPIO_PIN_RESET);

  Disable_TIM1_PWM();

  HAL_TIM_Encoder_Start(&htim3, TIM_CHANNEL_ALL);

  HAL_TIM_OC_Start(&htim2, TIM_CHANNEL_1); // tiempo update TIM1
  HAL_TIM_OC_Start(&htim2, TIM_CHANNEL_2); // está conectado a una compuerta XOR entre los pineas A y B del encoder y registra el tiempo en los cambios del encoder
  HAL_TIM_OC_Start(&htim2, TIM_CHANNEL_3); // tiempo encoder index

  HAL_TIM_OC_Start(&htim15, TIM_CHANNEL_1);
  HAL_TIM_OC_Start(&htim15, TIM_CHANNEL_2);

  HAL_ADCEx_Calibration_Start(&hadc1, ADC_CALIB_OFFSET, ADC_SINGLE_ENDED);
  // HAL_ADCEx_Calibration_Start(&hadc1, ADC_CALIB_OFFSET_LINEARITY, ADC_SINGLE_ENDED);
  HAL_ADCEx_InjectedStart(&hadc1); // medicien de corriente en fase

  HAL_ADCEx_Calibration_Start(&hadc2, ADC_CALIB_OFFSET, ADC_SINGLE_ENDED);
  // HAL_ADCEx_Calibration_Start(&hadc2, ADC_CALIB_OFFSET_LINEARITY, ADC_SINGLE_ENDED);
  HAL_ADC_Start_DMA(&hadc2, (uint32_t *)ADC2_DMA, ADC2_DMA_SAMPLES); // potenciometros

  HAL_ADCEx_Calibration_Start(&hadc3, ADC_CALIB_OFFSET, ADC_SINGLE_ENDED);
  // HAL_ADCEx_Calibration_Start(&hadc3, ADC_CALIB_OFFSET_LINEARITY, ADC_SINGLE_ENDED);
  HAL_ADC_Start_DMA(&hadc3, (uint32_t *)ADC3_DMA, ADC3_DMA_SAMPLES); // voltaje de bus, Vref e IC temp

  SM_clear_task(&SM);
  HAL_Delay(1);
  HAL_TIM_Base_Start_IT(&htim1);

  if (USB_Is_Connected())
    printf("FIN de configuracion\n");

#ifdef EN_DEBUG
  if (USB_Is_Connected())
  {
    printf("Debug Buffer len: %u\n", DEBUG_DATA_LEN);
    printf("Debug Data Size: %u\n", DEBUG_DATA_SIZE);
    printf("Packet Size: %u\n", PACKET_SIZE);
  }
  debug_data.EN_write = false;
  debug_data.EN_read = false;
#endif

  if (USB_Is_Connected())
  {
    printf("\n1/tau: %.10lf\n", CURRENT_FILTER_CUT_FREC);
    printf("P_GAIN: %.10lf\n", CURRENT_P_GAIN);
    printf("I_GAIN: %.10lf\n\n", CURRENT_I_GAIN);
  }

  SM_add_task(&SM, START_SECUENCE);
  HAL_Delay(1);
  SM_wait_IDLE(&SM);
  HAL_Delay(1);

  if (USB_Is_Connected())
  {
    printf("OFFSET_IA: %ld / OFFSET_IB: %ld / OFFSET_IC: %ld / Vbus: %.8f\n", CURRENT.phase_A.OFFSET, CURRENT.phase_B.OFFSET, CURRENT.phase_C.OFFSET, Vbus);
    HAL_Delay(5000);
  }

  /* USER CODE END 2 */

  /* Infinite loop */
  /* USER CODE BEGIN WHILE */
  while (1)
  {

    if (DebounceButton(&SW1) && SM.STATE != IDLE)
    {
      SM_force_stop();

      if (USB_Is_Connected())
        printf("SW1: STOP PWM\n");
    }

    if (DebounceButton(&SW2))
    {
      if (SM.STATE == IDLE)
      {
        //SM_add_task(&SM, START_PWM);

        SM_add_task(&SM, TEST_SVM_SIGNALS);
        // SM_add_task(&SM, TEST_PHASE);
        // SM_add_task(&SM, TEST_ANGLE_OPEN_LOOP);
        // SM_add_task(&SM, TEST_OPEN_LOOP);
        // SM_add_task(&SM, TEST_ENCODER_OPEN_LOOP);
        // SM_add_task(&SM, TEST_CLOSE_LOOP);
        // SM_add_task(&SM, TEST_VELOCITY_CLOSE_LOOP);
        if (USB_Is_Connected())
          printf("SW2: START PWM\n");
      }
#ifdef EN_DEBUG
      else
      {
        if (USB_Is_Connected())
          if (!debug_data.EN_write && !debug_data.EN_read)
          {
            printf("activando debug...\n");
            HAL_Delay(100);
            debug_data.first_index = 0;
            debug_data.last_index = 0;
            debug_data.EN_write = true;
            HAL_Delay(1);
            debug_data.EN_read = true;
          }
      }
#endif
    }

    if (DebounceButton(&SW3))
    {
      if (SM.STATE == IDLE)
      {
        SM_add_task(&SM, CALIB_SECUENCE);
        HAL_Delay(1);
        SM_wait_IDLE(&SM);
        HAL_Delay(100);
        if (USB_Is_Connected())
          printf("Encoder OFFSET: %.9f - Index OFFSER:%ld\n", ENCODER.OFFSET, (int32_t)ENCODER.RAW_BASE_POS);
        // HAL_Delay(5000);
      }
    }

#ifdef EN_DEBUG
    if (debug_data.EN_read)
    {
      debug_data.last_index = (debug_data.last_index + 1) % DEBUG_DATA_LEN;
      if (!debug_data.EN_write && debug_data.last_index == debug_data.first_index)
      {
        debug_data.EN_read = false;
        printf("FIN debug\n");
      }
      else
      {
        send_debug_data(&debug_data);
      }
    }
    else
    {
#endif
      static int64_t last_tick = 0;
      int64_t current_tick = TIMER_TICK.full;
      if (current_tick - last_tick >= ONE_MS_TICK * 100)
      {
        last_tick = current_tick;

        // printf("SM:%2d - encoder:%6.02f - Vbus:%7.03f - POT_A:%6.03f - POT_B:%6.03f - POT_C:%6.03f - I_A:%6.02f - I_B:%6.02f\n", SM.STATE, ENCODER.filter_global_theta.value, Vbus, POT_A, POT_B, POT_C, CURRENT.phase_A.filter.value, CURRENT.phase_B.filter.value);
        // printf("SM:%2d\n", SM.STATE);
        if (USB_Is_Connected())
        {
          switch (SM.STATE)
          {
          case IDLE:
            printf("Vbus:%8.03f - encoder:%8.03f - POT_A:%8.03f - POT_B:%8.03f - POT_C:%8.03f\n", Vbus, ENCODER.filter_global_theta.value, POT_A, POT_B, POT_C);
            break;

          case TEST_OPEN_LOOP:
          case TEST_ANGLE_OPEN_LOOP:
          case TEST_ENCODER_OPEN_LOOP:
            printf("Vbus:%6.02f - I_q:%6.02f - I_d:%6.02f - encoder:%8.03f - speed:%8.02f - SVM_q:%8.03f - SVM_d:%8.03f - SVM_theta:%8.03f - POT_A:%8.03f - POT_B:%8.03f - POT_C:%8.03f\n", Vbus, CURRENT.filter_q.value, CURRENT.filter_d.value, ENCODER.filter_global_theta.value, ENCODER.speed, SVM.Vq, SVM.Vd, SVM.theta / (float)MOTOR_POLE_PAIR, POT_A, POT_B, POT_C);
            break;

          case TEST_CLOSE_LOOP:
            printf("Vbus:%6.02f - I_q:%6.02f - I_d:%6.02f - encoder:%8.03f - speed:%8.02f - CI_q:%8.03f - CI_d:%8.03f\n", Vbus, CURRENT.filter_q.value, CURRENT.filter_d.value, ENCODER.filter_global_theta.value, ENCODER.speed, CURRENT_CONTROLLER.q.set_point, CURRENT_CONTROLLER.d.set_point);
            break;

          case TEST_VELOCITY_CLOSE_LOOP:
            printf("Vbus:%6.02f - I_q:%6.02f - I_d:%6.02f - encoder:%8.03f - speed:%8.02f - RPM:%8d - V_set:%8.03f - CI_q:%8.03f - CI_d:%8.03f\n", Vbus, CURRENT.filter_q.value, CURRENT.filter_d.value, ENCODER.filter_global_theta.value, ENCODER.speed, (int)(ENCODER.speed * 60.0), VELOCITY_CONTROLLER.set_point, CURRENT_CONTROLLER.q.set_point, CURRENT_CONTROLLER.d.set_point);
            break;

          default:
            printf("Vbus:%8.03f - I_A:%8.03f - I_B:%8.03f - I_C:%8.03f - encoder:%8.05f - speed:%8.05f - POT_A:%8.03f - POT_B:%8.03f - POT_C:%8.03f\n", Vbus, CURRENT.phase_A.filter.value, CURRENT.phase_B.filter.value, CURRENT.phase_C.filter.value, ENCODER.filter_global_theta.value, ENCODER.speed, POT_A, POT_B, POT_C);
            break;
          }
        }
      }
#ifdef EN_DEBUG
    }
#endif
    /* USER CODE END WHILE */

    /* USER CODE BEGIN 3 */
  }
  /* USER CODE END 3 */
}

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
/* USER CODE BEGIN 4 */

void HAL_TIM_PeriodElapsedCallback(TIM_HandleTypeDef *htim)
{
  if (htim->Instance == TIM1)
  {
    HAL_GPIO_WritePin(LED_LOOP_GPIO_Port, LED_LOOP_Pin, GPIO_PIN_SET);

    uint16_t RAW_ENCODER_POS = htim3.Instance->CNT;
    uint32_t RAW_ENCODER_UPDATE_TICK = htim2.Instance->CCR2;
    uint32_t RAW_ENCODER_INDEX_TICK = htim2.Instance->CCR3;
    uint32_t RAW_TIMER_TICK = htim2.Instance->CCR1;

    UPDATE_TIMER_TICK(TIMER_TICK, RAW_TIMER_TICK);

    bool encoder_is_update = UpdateTick(&ENCODER.UPDATE_TICK, RAW_ENCODER_UPDATE_TICK, &TIMER_TICK);
    bool index_is_update = UpdateTick(&ENCODER.INDEX_TICK, RAW_ENCODER_INDEX_TICK, &TIMER_TICK);

    update_encoder(&ENCODER, RAW_ENCODER_POS, TIMER_TICK.full);

    update_ADC(&ADC_VBUS, ADC3_DMA[0]);
    Vbus = ADC_VBUS.filter_value.value;

    update_ADC(&ADC_POT_A, ADC2_DMA[0]);
    POT_A = ABS_min_constrain(ADC_POT_A.filter_value.value, 0.02f);

    update_ADC(&ADC_POT_B, ADC2_DMA[1]);
    POT_B = ABS_min_constrain(ADC_POT_B.filter_value.value, 0.02f);

    update_ADC(&ADC_POT_C, ADC2_DMA[2]);
    POT_C = ABS_min_constrain(ADC_POT_C.filter_value.value, 0.02f);

    uint16_t RAW_A = HAL_ADCEx_InjectedGetValue(&hadc1, ADC_INJECTED_RANK_1);
    uint16_t RAW_B = HAL_ADCEx_InjectedGetValue(&hadc1, ADC_INJECTED_RANK_2);
    update_current_sensor(&CURRENT, RAW_A, RAW_B, SVM.theta);
    Ibus = CURRENT.filter_bus.value;

    if ((Vbus <= 10.0f && SM.STATE != TEST_SVM_SIGNALS) && (SVM.EN || PWM_EN))
    {
      SM_force_stop();
    }

    if (SM.STATE == IDLE && !SM_is_empty(&SM))
    {
      SM_update_task(&SM);
    }

    if (!__HAL_TIM_IS_TIM_COUNTING_DOWN(&htim1))
    {
      HAL_GPIO_WritePin(LED_WARNING_GPIO_Port, LED_WARNING_Pin, GPIO_PIN_RESET);

      static uint64_t UTIL_SM_TIME = 0;
      switch (SM.STATE)
      {
      case IDLE:
        if (PWM_EN)
        {
          SM_force_stop();
        }
        break;

      case START_PWM:
      {
        static bool start_flag = false;
        static int start_wait_count = 0;
        if (!start_flag)
        {
          htim1.Instance->CCR1 = 0;
          htim1.Instance->CCR2 = 0;
          htim1.Instance->CCR3 = 0;

          Enable_TIM1_PWM();

          start_flag = true;
          start_wait_count = 10;

          PWM_EN = false;
          SVM.EN = false;
        }
        else
        {
          start_wait_count--;

          if (start_wait_count <= 0)
          {
            ResetPIController(&VELOCITY_CONTROLLER);
            ResetControllerDQ(&CURRENT_CONTROLLER);
            start_flag = false;
            PWM_EN = true;
            SM_update_task(&SM);
          }
          else if (start_wait_count <= 2)
          {
            HAL_GPIO_WritePin(EN_GATE_GPIO_Port, EN_GATE_Pin, GPIO_PIN_SET);
          }
        }
        break;
      }

      case STOP_PWM:
      {
        static bool stop_flag = false;
        static int stop_wait_count = 0;
        if (!stop_flag)
        {
          htim1.Instance->CCR1 = 0;
          htim1.Instance->CCR2 = 0;
          htim1.Instance->CCR3 = 0;

          stop_flag = true;
          stop_wait_count = 10;

          PWM_EN = false;
          SVM.EN = false;
        }
        else
        {
          stop_wait_count--;

          if (stop_wait_count <= 0)
          {
            stop_flag = false;
            Disable_TIM1_PWM();
            SM_update_task(&SM);
          }
          else if (stop_wait_count <= 2)
          {
            HAL_GPIO_WritePin(EN_GATE_GPIO_Port, EN_GATE_Pin, GPIO_PIN_RESET);
          }
        }
        break;
      }

      case START_SECUENCE:
        // SM_add_task(&SM, START_PWM);
        SM_add_task(&SM, ADC_OFFSET_CALIB);
        // SM_add_task(&SM, STOP_PWM);

        UTIL_SM_TIME = TIMER_TICK.full;

        SM_update_task(&SM);
        break;

      case ADC_OFFSET_CALIB:
        update_current_offset(&CURRENT, RAW_A, RAW_B, false);

        if (TIMER_TICK.full - UTIL_SM_TIME >= ONE_MS_TICK * 50)
        {
          update_current_offset(&CURRENT, RAW_A, RAW_B, true);
          UTIL_SM_TIME = TIMER_TICK.full;
          SM_update_task(&SM);
        }
        break;

      case CALIB_SECUENCE:
        SM_add_task(&SM, START_PWM);
        SM_add_task(&SM, GO_INDEX);

#ifndef OFFSET_HOME
        SM_add_task(&SM, OFFSET_CALIB);
        ENCODER.OFFSET = 0.0f;
#endif

        SM_add_task(&SM, STOP_PWM);

        SVM.Vq = 0.0f;
        SVM.Vd = 0.0f;
        SVM.DIR = 1;
        SVM.EN = false;

        if (ENCODER.OFFSET == 0.0f)
          SVM.theta = 0.0f;
        else
          SVM.theta = ENCODER.electric_theta;

        UTIL_SM_TIME = TIMER_TICK.full;

        SM_update_task(&SM);
        break;

      case GO_INDEX:
        SVM.EN = true;
        SVM.Vq = CALIB_VOLTAGE_q;
        SVM.Vd = CALIB_VOLTAGE_d;
        if (index_is_update)
        {
          update_index_offset(&ENCODER);

          UTIL_SM_TIME = TIMER_TICK.full;
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

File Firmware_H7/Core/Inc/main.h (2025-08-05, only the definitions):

#define START_PERIOD 0
#define DEAD_TIME 50
#define TIMER_ADC_CCR (TIMER_PERIOD - TIMER_ADC_DELTA)
#define TIMER_ADC_DELTA 24
#define TIMER_PERIOD 5000
#define INPUT_FILTER 4
#define TIMER_PRESCALER 0
#define TIMER_REPETICION_COUNTER 0
#define SW_1_Pin GPIO_PIN_2
#define SW_1_GPIO_Port GPIOE
#define SW_2_Pin GPIO_PIN_3
#define SW_2_GPIO_Port GPIOE
#define SW_3_Pin GPIO_PIN_4
#define SW_3_GPIO_Port GPIOE
#define LED_WARNING_Pin GPIO_PIN_13
#define LED_WARNING_GPIO_Port GPIOC
#define LED_LOOP_Pin GPIO_PIN_14
#define LED_LOOP_GPIO_Port GPIOC
#define LED_STATE_Pin GPIO_PIN_15
#define LED_STATE_GPIO_Port GPIOC
#define OSC_IN_Pin GPIO_PIN_0
#define OSC_IN_GPIO_Port GPIOH
#define OSC_OUT_Pin GPIO_PIN_1
#define OSC_OUT_GPIO_Port GPIOH
#define POT_B_Pin GPIO_PIN_0
#define POT_B_GPIO_Port GPIOC
#define POR_C_Pin GPIO_PIN_1
#define POR_C_GPIO_Port GPIOC
#define VBUS_S_Pin GPIO_PIN_2
#define VBUS_S_GPIO_Port GPIOC
#define CURR_A_Pin GPIO_PIN_6
#define CURR_A_GPIO_Port GPIOA
#define CURR_B_Pin GPIO_PIN_4
#define CURR_B_GPIO_Port GPIOC
#define POT_A_Pin GPIO_PIN_0
#define POT_A_GPIO_Port GPIOB
#define CURR_C_Pin GPIO_PIN_1
#define CURR_C_GPIO_Port GPIOB
#define LINA_Pin GPIO_PIN_8
#define LINA_GPIO_Port GPIOE
#define HINA_Pin GPIO_PIN_9
#define HINA_GPIO_Port GPIOE
#define LINB_Pin GPIO_PIN_10
#define LINB_GPIO_Port GPIOE
#define HINB_Pin GPIO_PIN_11
#define HINB_GPIO_Port GPIOE
#define LINC_Pin GPIO_PIN_12
#define LINC_GPIO_Port GPIOE
#define HINC_Pin GPIO_PIN_13
#define HINC_GPIO_Port GPIOE
#define EN_GATE_Pin GPIO_PIN_14
#define EN_GATE_GPIO_Port GPIOE
#define ENC_INDEX_Pin GPIO_PIN_10
#define ENC_INDEX_GPIO_Port GPIOB
#define SPI_NSS_Pin GPIO_PIN_12
#define SPI_NSS_GPIO_Port GPIOB
#define SPI_SCK_Pin GPIO_PIN_13
#define SPI_SCK_GPIO_Port GPIOB
#define SPI_MISO_Pin GPIO_PIN_14
#define SPI_MISO_GPIO_Port GPIOB
#define SPI_MOSI_Pin GPIO_PIN_15
#define SPI_MOSI_GPIO_Port GPIOB
#define USB_DM_Pin GPIO_PIN_11
#define USB_DM_GPIO_Port GPIOA
#define USB_DP_Pin GPIO_PIN_12
#define USB_DP_GPIO_Port GPIOA
#define SWDIO_Pin GPIO_PIN_13
#define SWDIO_GPIO_Port GPIOA
#define SWCLK_Pin GPIO_PIN_14
#define SWCLK_GPIO_Port GPIOA
#define SBUS_Pin GPIO_PIN_15
#define SBUS_GPIO_Port GPIOA
#define SPORT_Pin GPIO_PIN_12
#define SPORT_GPIO_Port GPIOC
#define UART_RX_Pin GPIO_PIN_0
#define UART_RX_GPIO_Port GPIOD
#define UART_TX_Pin GPIO_PIN_1
#define UART_TX_GPIO_Port GPIOD
#define ENC_XOR_Pin GPIO_PIN_3
#define ENC_XOR_GPIO_Port GPIOB
#define ENC_A_Pin GPIO_PIN_4
#define ENC_A_GPIO_Port GPIOB
#define ENC_B_Pin GPIO_PIN_5
#define ENC_B_GPIO_Port GPIOB

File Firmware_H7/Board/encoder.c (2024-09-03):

#include "encoder.h"

void update_index_offset(EncoderSystem *encoder)
{
    encoder->RAW_BASE_POS -= encoder->RAW_POS;
}

void update_encoder_offset(EncoderSystem *encoder, float SVM_theta, int SVM_DIR, bool set)
{
    static double OFFSET_UP_SUM = 0.0;
    static int32_t OFFSET_UP_count = 0;

    static double OFFSET_DOWN_SUM = 0.0;
    static int32_t OFFSET_DOWN_count = 0;

    if (set)
    {
        double offset_up = OFFSET_UP_SUM / (double)OFFSET_UP_count;
        double offset_down = OFFSET_DOWN_SUM / (double)OFFSET_DOWN_count;
        double offset = (offset_up + offset_down) / 2.0;

        encoder->OFFSET = (float)offset;

        OFFSET_UP_SUM = 0.0;
        OFFSET_UP_count = 0;

        OFFSET_DOWN_SUM = 0.0;
        OFFSET_DOWN_count = 0;
    }
    else
    {
        double delta = (double)encoder->global_theta - (SVM_theta / (double)MOTOR_POLE_PAIR);
        if (SVM_DIR)
        {
            OFFSET_UP_SUM += delta;
            OFFSET_UP_count++;
        }
        else
        {
            OFFSET_DOWN_SUM += delta;
            OFFSET_DOWN_count++;
        }
    }
}

/**
 * @brief Actualiza los datos del sistema del encoder.
 *
 * Esta función actualiza la posición, velocidad y aceleración del encoder en función de la nueva posición cruda
 * del encoder y el tiempo global.
 *
 * @param encoder Puntero a la estructura EncoderSystem que contiene los datos del encoder.
 * @param raw_encoder_pos Posición cruda del encoder.
 * @param global_tick Valor global del tick.
 * @retval None
 */
void update_encoder(EncoderSystem *encoder, uint16_t raw_encoder_pos, int64_t global_tick)
{
    if (raw_encoder_pos != encoder->last_RAW_VALUE)
    {
        encoder->RAW_VALUE = raw_encoder_pos;

        int32_t diff = raw_encoder_pos - encoder->last_RAW_VALUE;
        if (diff > 0x7FFF)
        {
            encoder->RAW_BASE_POS -= 0x10000;
        }
        else if (diff < -0x7FFF)
        {
            encoder->RAW_BASE_POS += 0x10000;
        }
        encoder->last_RAW_VALUE = raw_encoder_pos;

        encoder->RAW_POS = encoder->RAW_BASE_POS + raw_encoder_pos;
        encoder->RAW_theta = encoder->RAW_POS % ENCODER_PPR;

        encoder->buffer_index = (encoder->buffer_index + 1) % ENCODER_BUFFER_SIZE;
        encoder->buffer[encoder->buffer_index].position = encoder->RAW_POS;
        encoder->buffer[encoder->buffer_index].time = encoder->UPDATE_TICK.full;

        float theta = ((float)encoder->RAW_theta * (float)ENCODER_TPP) - encoder->OFFSET;
        encoder->theta = circular_constrain(theta);

        uint32_t firstIndex = (encoder->buffer_index + 1) % ENCODER_BUFFER_SIZE;
        while (firstIndex != encoder->buffer_index && (global_tick - encoder->buffer[firstIndex].time) > ENCODER_MAX_TICK_DIFF)
        {
            firstIndex = (firstIndex + 1) % ENCODER_BUFFER_SIZE;
        }

        if (firstIndex == encoder->buffer_index)
        {
            encoder->speed = 0.0f;
            encoder->acceleration = 0.0f;
        }
        else
        {
            int64_t encoder_delta_pos = encoder->buffer[encoder->buffer_index].position - encoder->buffer[firstIndex].position;
            int64_t encoder_delta_time = encoder->buffer[encoder->buffer_index].time - encoder->buffer[firstIndex].time;

            if (encoder_delta_time == 0 || encoder_delta_pos == 0)
            {
                encoder->speed = 0.0f;
                encoder->acceleration = 0.0f;
                encoder->buffer[encoder->buffer_index].speed = 0.0f;
            }
            else
            {
                float dt = ((float)encoder_delta_time * TIMER_TIME_PERIOD);
                encoder->speed = (float)((float)encoder_delta_pos * (float)ENCODER_TPP) / dt;
                encoder->buffer[encoder->buffer_index].speed = encoder->speed;
                encoder->acceleration = (encoder->speed - encoder->buffer[firstIndex].speed) / dt;
            }
        }

        encoder->global_theta = ((float)encoder->RAW_POS * (float)ENCODER_TPP) - encoder->OFFSET;
    }
    else if (global_tick - encoder->buffer[encoder->buffer_index].time > ENCODER_MAX_TICK_DIFF)
    {
        encoder->speed = 0.0f;
        encoder->acceleration = 0.0f;
    }

    int64_t dt_tick = global_tick - encoder->buffer[encoder->buffer_index].time;
    float dt = (float)((double)dt_tick * TIMER_TIME_PERIOD);
    float d_theta = encoder->speed * dt;
    float electric_theta = (encoder->theta + d_theta) * (float)MOTOR_POLE_PAIR;
    encoder->electric_theta = circular_constrain(electric_theta);

    update_filtered_value(&encoder->filter_global_theta, encoder->global_theta);
    update_filtered_value(&encoder->filter_speed, encoder->speed);
    update_filtered_value(&encoder->filter_acceleration, encoder->acceleration);
}

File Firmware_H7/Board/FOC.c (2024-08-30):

#include "FOC.h"
#include "arm_math.h"

#include "board.h"

/**
 * @brief Genera los tiempos de activación para las señales PWM usando la técnica SVM.
 * 
 * @param alpha Componente alfa del vector de referencia.
 * @param beta Componente beta del vector de referencia.
 * @param tA Tiempo de activación para la fase A.
 * @param tB Tiempo de activación para la fase B.
 * @param tC Tiempo de activación para la fase C.
 * @return true Si los tiempos de activación son válidos.
 * @return false Si los tiempos de activación no son válidos.
 */
bool SVMTransform(float alpha, float beta, float *tA, float *tB, float *tC)
{
    int Sextant;

    if (beta >= 0.0f)
    {
        if (alpha >= 0.0f)
        {
            // quadrant I
            if (one_by_sqrt3 * beta > alpha)
                Sextant = 2; // sextant v2-v3
            else
                Sextant = 1; // sextant v1-v2
        }
        else
        {
            // quadrant II
            if (-one_by_sqrt3 * beta > alpha)
                Sextant = 3; // sextant v3-v4
            else
                Sextant = 2; // sextant v2-v3
        }
    }
    else
    {
        if (alpha >= 0.0f)
        {
            // quadrant IV
            if (-one_by_sqrt3 * beta > alpha)
                Sextant = 5; // sextant v5-v6
            else
                Sextant = 6; // sextant v6-v1
        }
        else
        {
            // quadrant III
            if (one_by_sqrt3 * beta > alpha)
                Sextant = 4; // sextant v4-v5
            else
                Sextant = 5; // sextant v5-v6
        }
    }

    switch (Sextant)
    {
    // sextant v1-v2
    case 1:
    {
        // Vector on-times
        float t1 = alpha - one_by_sqrt3 * beta;
        float t2 = two_by_sqrt3 * beta;

        // PWM timings
        *tA = (1.0f - t1 - t2) * 0.5f;
        *tB = *tA + t1;
        *tC = *tB + t2;
    }
    break;

    // sextant v2-v3
    case 2:
    {
        // Vector on-times
        float t2 = alpha + one_by_sqrt3 * beta;
        float t3 = -alpha + one_by_sqrt3 * beta;

        // PWM timings
        *tB = (1.0f - t2 - t3) * 0.5f;
        *tA = *tB + t3;
        *tC = *tA + t2;
    }
    break;

    // sextant v3-v4
    case 3:
    {
        // Vector on-times
        float t3 = two_by_sqrt3 * beta;
        float t4 = -alpha - one_by_sqrt3 * beta;

        // PWM timings
        *tB = (1.0f - t3 - t4) * 0.5f;
        *tC = *tB + t3;
        *tA = *tC + t4;
    }
    break;

    // sextant v4-v5
    case 4:
    {
        // Vector on-times
        float t4 = -alpha + one_by_sqrt3 * beta;
        float t5 = -two_by_sqrt3 * beta;

        // PWM timings
        *tC = (1.0f - t4 - t5) * 0.5f;
        *tB = *tC + t5;
        *tA = *tB + t4;
    }
    break;

    // sextant v5-v6
    case 5:
    {
        // Vector on-times
        float t5 = -alpha - one_by_sqrt3 * beta;
        float t6 = alpha - one_by_sqrt3 * beta;

        // PWM timings
        *tC = (1.0f - t5 - t6) * 0.5f;
        *tA = *tC + t5;
        *tB = *tA + t6;
    }
    break;

    // sextant v6-v1
    case 6:
    {
        // Vector on-times
        float t6 = -two_by_sqrt3 * beta;
        float t1 = alpha + one_by_sqrt3 * beta;

        // PWM timings
        *tA = (1.0f - t6 - t1) * 0.5f;
        *tC = *tA + t1;
        *tB = *tC + t6;
    }
    break;
    }

    bool result_valid =
        *tA >= 0.0f && *tA <= 1.0f && *tB >= 0.0f && *tB <= 1.0f && *tC >= 0.0f && *tC <= 1.0f;
    return result_valid;
}

/**
 * @brief Realiza la transformación inversa de Park.
 * 
 * @param d Componente d del sistema de coordenadas dq.
 * @param q Componente q del sistema de coordenadas dq.
 * @param theta Ángulo de la rotación.
 * @param alpha Componente alfa del sistema de coordenadas alfa-beta.
 * @param beta Componente beta del sistema de coordenadas alfa-beta.
 */
void InverseParkTransform(float d, float q, float theta, float *alpha, float *beta)
{
    float sin_value;
    float cos_value;

    arm_sin_cos_f32(theta * 360.0f, &sin_value, &cos_value);

    arm_inv_park_f32(d, q, alpha, beta, sin_value, cos_value);
}

/**
 * @brief Realiza la transformación inversa de Park y la modulación por vector espacial (SVMTransform).
 * 
 * @param Vd Componente d del voltaje.
 * @param Vq Componente q del voltaje.
 * @param Vbus Voltaje del bus.
 * @param theta Ángulo de la rotación.
 * @param tA Tiempo de activación para la fase A.
 * @param tB Tiempo de activación para la fase B.
 * @param tC Tiempo de activación para la fase C.
 * @return true Si la transformación es válida.
 * @return false Si la transformación no es válida.
 */
bool InverseParkAndSVM(SVM_data_t *SVM, float Vbus)
{
    float modVd = SVM->Vd / Vbus;
    float modVq = SVM->Vq / Vbus;

    float modVdq = 0;
    arm_sqrt_f32((modVd * modVd) + (modVq * modVq), &modVdq);

    if (modVdq > MAX_V_MOD)
    {
        float scalingFactor = MAX_V_MOD / modVdq;
        modVd *= scalingFactor;
        modVq *= scalingFactor;
    }

    SVM->Vdq = modVdq * Vbus;

    InverseParkTransform(modVd, modVq, SVM->theta, &SVM->alpha, &SVM->beta);
    return SVMTransform(SVM->alpha, SVM->beta, &SVM->tA, &SVM->tB, &SVM->tC);
}

/**
 * @brief Realiza la transformación de Park.
 * 
 * @param alpha Componente alfa del sistema de coordenadas alfa-beta.
 * @param beta Componente beta del sistema de coordenadas alfa-beta.
 * @param theta Ángulo de la rotación.
 * @param d Componente d del sistema de coordenadas dq.
 * @param q Componente q del sistema de coordenadas dq.
 */
void ParkTransform(float alpha, float beta, float theta, float *d, float *q)
{
    float rad_theta = (theta * 2.0f * PI);

    float sin_value;
    float cos_value;

    sin_value = arm_sin_f32(rad_theta);
    cos_value = arm_cos_f32(rad_theta);

    /* Calculate pId using the equation, pId = Ialpha * cosVal + Ibeta * sinVal */
    *d = -((alpha * cos_value) + (beta * sin_value));

    /* Calculate pIq using the equation, pIq = - Ialpha * sinVal + Ibeta * cosVal */
    *q = -((beta * cos_value) - (alpha * sin_value));
}

/**
 * @brief Realiza la transformación de Clarke.
 * 
 * @param Ia Corriente de fase A.
 * @param Ib Corriente de fase B.
 * @param Ialpha Componente alfa de la corriente.
 * @param Ibeta Componente beta de la corriente.
 */
void ClarkeTransform(float Ia, float Ib, float *Ialpha, float *Ibeta)
{
    /* Calculate pIalpha using the equation, pIalpha = Ia */
    *Ialpha = Ia;

    /* Calculate pIbeta using the equation, pIbeta = (1/sqrt(3)) * Ia + (2/sqrt(3)) * Ib */
    *Ibeta = ((one_by_sqrt3 * Ia) + (two_by_sqrt3 * Ib));
}
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

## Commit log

2024-06-23 add V0 harware
    [STM32_esc.brd, STM32_esc.sch]
2024-06-23 debug code
    [parametros.txt]
2024-07-28 firmware y hardware update
    [EZFOC_V1.brd, EZFOC_V1.sch, EZFOC_V1_bom.csv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]
2024-07-29 modelos 3D base de pruebas
    [Base_PCB.ipt, Base_PCB.stl, base_motor.iam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]
2024-07-29 uso ADC 2
2024-09-14 manuscrito semana 1
    [adquisicion.csv, alta velocidad y encoder.csv, controladores.csv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]
2025-08-05 reorganización
    [Base_PCB inclinada.stl, EZFOC_V1.brd, EZFOC_V1.sch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]

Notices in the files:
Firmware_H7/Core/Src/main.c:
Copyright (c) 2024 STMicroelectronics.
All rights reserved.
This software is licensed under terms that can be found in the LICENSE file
